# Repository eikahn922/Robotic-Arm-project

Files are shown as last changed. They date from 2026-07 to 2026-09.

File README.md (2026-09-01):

# Robotic Arm Project

This repository documents the mechanical design, engineering analysis, and ROS 2 development of a robotic arm with three arm joints, a wrist, and a mimic-driven gripper. It is organized so each stage can be reviewed and reproduced independently.

## Project artifacts

| Area | Artifact | Description |
| --- | --- | --- |
| Active timeline | [3-DOF Robotic Arm Project Timeline](docs/project-workflow/PROJECT_TIMELINE.md) | Daily development plan through August 18, including remote-work constraints and completion criteria. |
| Physical build | [Parts List and Purchase Tracker](physical-build/README.md) | Torque-driven actuator selection, power distribution, wiring, fasteners, camera plan, and purchase tracker. |
| ROS 2 progress | [ROS 2 Progress](ROS_PROGRESS.md) | Recruiter-friendly milestone log covering the completed setup, URDF/Xacro model, RViz result, lessons learned, and next steps. |
| ROS 2 package | [robot_arm_description](ros2_ws/src/robot_arm_description) | Reproducible ROS 2 Jazzy package containing the complete CAD geometry — base, waist, upper arm, forearm, wrist, and all seven gripper part instances — with five commanded joints and a mimic gripper side. |
| Ubuntu VM guide | [VM Handoff](docs/VM_HANDOFF.md) | Exact Ubuntu 24.04 ARM64 commands to update, build, launch, and troubleshoot the RViz visualization. |
| Control & simulation | [Simulation Guide](docs/SIMULATION.md) | Per-layer status, `ros2_control` test commands, and the list of assumptions not yet verified at runtime. |
| Model validation | [validate_model.py](ros2_ws/src/robot_arm_description/test/validate_model.py) | Dependency-free static validation of the URDF tree, meshes, collision, inertials, and controller configuration. |
| ROS 2 base mesh | [base_link.stl](ros2_ws/src/robot_arm_description/STL/base_link.stl) | Meter-scaled binary STL exported from SolidWorks for the fixed robot base. |
| ROS 2 waist mesh | [waist_link.stl](ros2_ws/src/robot_arm_description/STL/waist_link.stl) | Meter-scaled binary STL exported from SolidWorks for the rotating waist link. |
| ROS 2 upper-arm mesh | [upper_arm_link.stl](ros2_ws/src/robot_arm_description/STL/upper_arm_link.stl) | Meter-scaled binary STL with a shoulder-centered origin and 120 mm shoulder-to-elbow spacing. |
| ROS 2 forearm mesh | [forearm_link.stl](ros2_ws/src/robot_arm_description/STL/forearm_link.stl) | Millimeter-scaled binary STL for Link #2, converted to meters and aligned to the STEP assembly in Xacro. |
| Project workflow | [Robotic Arm Project Workflow](docs/project-workflow/Robotic-Arm-Project-Workflow.pdf) | Detailed engineering and implementation workflow for the project. |
| Engineering analysis | [Torque and Servo Sizing Analysis](analysis/README.md) | Formula-driven shoulder and elbow torque calculations, assumptions, results, and validation plan. |
| Calculation workbook | [3DOF Robotic Arm Torque & Servo Sizing Analysis](analysis/3DOF-Robotic-Arm-Torque-Servo-Sizing-Analysis.xlsx) | Downloadable workbook containing the full servo-sizing calculation model. |
| Final assembly | [Robot Arm Final Assembly](cad/assembly/Robot-Arm-Final-Assembly.SLDASM) | Complete SolidWorks assembly for the robot arm. |
| CAD — base | [Robot Arm Base v1](cad/base/Robot-Arm-Base-v1.SLDPRT) | SolidWorks part model for the robot arm's structural base. |
| CAD — gripper gear | [gearRobotArm.SLDPRT](cad/gripper/gearRobotArm.SLDPRT) | SolidWorks part model for the gripper gear. |
| CAD — gripper connecting link | [Robot Arm Gripper Connecting Link](cad/all-links/Robot-Arm-Gripper-Connecting-Link.SLDPRT) | SolidWorks part model for the gripper connecting link. |
| CAD — gripper first link | [Robot Arm Gripper First Link](cad/gripper/Robot-Arm-Gripper-First-Link.SLDPRT) | SolidWorks part model for the first gripper link. |
| CAD — gripper link | [Robot Arm Gripper Link 1](cad/gripper/Robot-Arm-Gripper-Link-1.SLDPRT) | SolidWorks part model for the gripper connection link. |
| CAD — link 1 | [Robot Arm Link 1](cad/all-links/Robot-Arm-Link-1.SLDPRT) | SolidWorks part model for the first structural arm link. |
| CAD — link 2 | [Robot Arm Link 2](cad/all-links/Robot-Arm-Link-2.SLDPRT) | SolidWorks part model for the second structural arm link. |
| CAD — link 3 | [Robot Arm Link 3](cad/all-links/Robot-Arm-Link-3.SLDPRT) | SolidWorks part model for the third structural arm link. |
| CAD — servo | [MG996R_servo.SLDPRT](cad/servo/MG996R_servo.SLDPRT) | SolidWorks part model for the MG996R servo. |
| CAD — servo | [SG90 - Micro Servo 9g - Tower Pro.1.SLDPRT](cad/servo/SG90%20-%20Micro%20Servo%209g%20-%20Tower%20Pro.1.SLDPRT) | SolidWorks part model for the Tower Pro SG90 micro servo. |
| CAD — waist | [Robot Arm Waist v1](cad/waist/Robot-Arm-Waist-v1.SLDPRT) | SolidWorks part model for the rotating waist component. |

## Repository structure

```text
.
├── cad/
│   ├── README.md
│   ├── assembly/
│   │   ├── README.md
│   │   └── Robot-Arm-Final-Assembly.SLDASM
│   ├── base/
│   │   └── Robot-Arm-Base-v1.SLDPRT
│   ├── gripper/
│   │   ├── Robot-Arm-Gripper-First-Link.SLDPRT
│   │   ├── Robot-Arm-Gripper-Link-1.SLDPRT
│   │   └── gearRobotArm.SLDPRT
│   ├── all-links/
│   │   ├── Robot-Arm-Gripper-Connecting-Link.SLDPRT
│   │   ├── Robot-Arm-Link-1.SLDPRT
│   │   ├── Robot-Arm-Link-2.SLDPRT
│   │   └── Robot-Arm-Link-3.SLDPRT
│   ├── servo/
│   │   ├── MG996R_servo.SLDPRT
│   │   └── SG90 - Micro Servo 9g - Tower Pro.1.SLDPRT
│   └── waist/
│       └── Robot-Arm-Waist-v1.SLDPRT
├── analysis/
│   ├── README.md
│   └── 3DOF-Robotic-Arm-Torque-Servo-Sizing-Analysis.xlsx
├── physical-build/
│   └── README.md
├── ros2_ws/
│   ├── README.md
│   └── src/
│       └── robot_arm_description/
│           ├── CMakeLists.txt
│           ├── package.xml
│           ├── STL/
│           │   ├── README.md
│           │   ├── base_link.stl
│           │   ├── upper_arm_link.stl
│           │   └── waist_link.stl
│           ├── launch/
│           ├── rviz/
│           └── urdf/
├── ROS_PROGRESS.md
└── docs/
    ├── images/
    │   └── ros/
    │       └── rviz-placeholder-arm.png
    └── project-workflow/
        ├── PROJECT_TIMELINE.md
        └── Robotic-Arm-Project-Workflow.pdf
```

## File formats

- `.SLDASM` files are native SolidWorks assemblies that reference component documents.
- `.SLDPRT` files are native SolidWorks part models.
- `.md` files contain repository-readable project plans and documentation.
- `.pdf` files contain project documentation suitable for viewing without CAD software.
- `.xlsx` files contain formula-driven engineering calculations and design inputs.
- `.xacro` files define parameterized robot links, joints, origins, axes, and limits for ROS 2.
- `.py` launch files start and configure the ROS 2 visualization nodes.
- `.stl` files contain meter-scaled binary geometry exported from SolidWorks for ROS visualization.

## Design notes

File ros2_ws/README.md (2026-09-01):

# ROS 2 Workspace

This directory contains the ROS 2 Jazzy packages for the 3-DOF robotic arm. See [ROS_PROGRESS.md](../ROS_PROGRESS.md) for the completed milestones, lessons learned, and next steps.

## Build and launch

Copy or clone this repository into an Ubuntu 24.04 environment with ROS 2 Jazzy installed, then run:

```bash
cd ros2_ws
colcon build --symlink-install --packages-select robot_arm_description
source install/setup.bash
LIBGL_ALWAYS_SOFTWARE=1 \
MESA_LOADER_DRIVER_OVERRIDE=llvmpipe \
QT_X11_NO_MITSHM=1 \
ros2 launch robot_arm_description display.launch.py
```

The three environment variables force software rendering, which the current UTM virtual machine
requires. They may be omitted on a native Linux system with working OpenGL acceleration.

See [docs/VM_HANDOFF.md](../docs/VM_HANDOFF.md) for the full Ubuntu VM update, build, launch, and
troubleshooting procedure.

## What this package currently is

An RViz **kinematic visualization**: `robot_state_publisher` publishes the TF tree from the URDF,
`joint_state_publisher_gui` provides sliders, and RViz draws the meshes. There is no physics engine.
Gazebo Sim and `ros2_control` are not implemented yet.

## Joint controls

`joint_state_publisher_gui` exposes six sliders:

| Joint | Type | Axis | Limits (rad) | Basis |
| --- | --- | --- | --- | --- |
| `base_yaw_joint` | revolute | `0 0 1` | −3.1416 to 3.1416 | provisional |
| `shoulder_joint` | revolute | `0 1 0` | −1.5708 to 1.5708 | provisional |
| `elbow_joint` | revolute | `0 1 0` | −2.0944 to 2.0944 | provisional |
| `wrist_roll_joint` | revolute | `0 0 1` | −3.1416 to 3.1416 | provisional |
| `wrist_pitch_joint` | revolute | `1 0 0` | −1.5708 to 1.5708 | provisional |
| `gripper_joint` | revolute | `0 0 1` | 0 to 0.75 | provisional; 0 = closed, 0.75 = 51.8 mm |

Three joints follow `gripper_joint` through URDF `mimic` tags and are deliberately not independent
controls: `right_gripper_joint` (opposing side) and `left_finger_joint` / `right_finger_joint`
(the parallelogram counter-rotation that keeps the jaw faces from fanning open).

## Link tree

```text
base_link
└── base_yaw_joint      (revolute)  → waist_link
    └── shoulder_joint  (revolute)  → upper_arm_link
        └── elbow_joint (revolute)  → forearm_link
            └── wrist_roll_joint  (revolute) → wrist_link
                └── wrist_pitch_joint (revolute) → gripper_base_link
                    ├── gripper_joint        (revolute) → left_gear_link
                    │   └── left_finger_joint  (mimic)  → left_finger_link
                    └── right_gripper_joint  (mimic)    → right_gear_link
                        └── right_finger_joint (mimic)  → right_finger_link
```

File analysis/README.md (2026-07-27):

# Torque and Servo Sizing Analysis

This folder documents the preliminary static torque analysis used to evaluate the MG996R servos for the shoulder and elbow joints of the 3-DOF robotic arm.

## Analysis artifacts

- [Calculation workbook](3DOF-Robotic-Arm-Torque-Servo-Sizing-Analysis.xlsx) — formula-driven engineering workbook with inputs, source notes, joint calculations, utilization, safety margins, and a comparison chart.
- [Live Google Sheet](https://docs.google.com/spreadsheets/d/17cgYGMoWEYcnl7br5cGeY7KRNHN3UeBQPRdlAbZkqd0/edit) — browser-accessible version of the same analysis.

## Method

The arm was evaluated in a conservative horizontal pose, where gravity produces the largest moment about the shoulder and elbow axes. For each joint, the static and design torques are calculated as:

```text
arm torque     = moving mass x gravity x center-of-mass radius
payload torque = payload mass x gravity x payload radius
static torque  = arm torque + payload torque
design torque  = static torque x safety factor
```

The model uses a 10 g payload representing a small foam ball, a safety factor of 2.0, and the MG996R advertised stall torque of 11 kgf-cm at 6 V. Masses and centers of mass come from the SolidWorks assembly after assigning PLA to the printed parts.

## Results

| Joint | Moving mass | COM radius | Static torque | Design torque | Servo utilization | Torque margin |
| --- | ---: | ---: | ---: | ---: | ---: | ---: |
| Elbow | 217.60 g | 76.46 mm | 1.94 kgf-cm | 3.88 kgf-cm | 35.3% | 2.83x |
| Shoulder | 297.31 g | 116.65 mm | 3.82 kgf-cm | 7.65 kgf-cm | 69.5% | 1.44x |

Both joints pass this preliminary static comparison. The shoulder is the limiting joint and therefore receives priority during physical testing.

## Engineering limitations and validation plan

- Advertised stall torque is a short-duration maximum, not a continuous operating rating.
- The current CAD masses treat modeled printed parts as solid PLA. Slicer-estimated printed masses should replace them after infill, wall count, and hardware are finalized.
- Wiring, fasteners, bearings, servo horns, and other unmodeled hardware must be added to the moving mass.
- The completed arm should be bench-tested at reduced command speed while measuring supply voltage, current draw, holding performance, temperature, and joint deflection.
- If the shoulder overheats, stalls, or sags, reduce reach or mass, add a spring/counterbalance, or select a higher-torque actuator.

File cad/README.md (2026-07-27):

# CAD Models

CAD files are grouped by robot subsystem so the repository can grow without mixing unrelated components.

## Final Assembly

- [`assembly/Robot-Arm-Final-Assembly.SLDASM`](assembly/Robot-Arm-Final-Assembly.SLDASM) contains the final robot arm assembly.
- [`assembly/README.md`](assembly/README.md) explains how to verify and package its external component references.

## Base

- [`base/Robot-Arm-Base-v1.SLDPRT`](base/Robot-Arm-Base-v1.SLDPRT) contains the first SolidWorks model of the structural base.

## Gripper

- [`gripper/gearRobotArm.SLDPRT`](gripper/gearRobotArm.SLDPRT) contains the gripper gear model.
- [`gripper/Robot-Arm-Gripper-First-Link.SLDPRT`](gripper/Robot-Arm-Gripper-First-Link.SLDPRT) contains the first gripper link.
- [`gripper/Robot-Arm-Gripper-Link-1.SLDPRT`](gripper/Robot-Arm-Gripper-Link-1.SLDPRT) contains the existing gripper link component.

## All Links

- [`all-links/Robot-Arm-Gripper-Connecting-Link.SLDPRT`](all-links/Robot-Arm-Gripper-Connecting-Link.SLDPRT) contains the gripper connecting link.
- [`all-links/Robot-Arm-Link-1.SLDPRT`](all-links/Robot-Arm-Link-1.SLDPRT) contains the first structural arm link.
- [`all-links/Robot-Arm-Link-2.SLDPRT`](all-links/Robot-Arm-Link-2.SLDPRT) contains the second structural arm link.
- [`all-links/Robot-Arm-Link-3.SLDPRT`](all-links/Robot-Arm-Link-3.SLDPRT) contains the third structural arm link.

## Servo

- [`servo/MG996R_servo.SLDPRT`](servo/MG996R_servo.SLDPRT) contains the MG996R servo model.
- [`servo/SG90 - Micro Servo 9g - Tower Pro.1.SLDPRT`](servo/SG90%20-%20Micro%20Servo%209g%20-%20Tower%20Pro.1.SLDPRT) contains the Tower Pro SG90 micro-servo model.

## Waist

- [`waist/Robot-Arm-Waist-v1.SLDPRT`](waist/Robot-Arm-Waist-v1.SLDPRT) contains the first SolidWorks model of the rotating waist component.

Future revisions should increment the version number while retaining older versions when they document meaningful design changes.

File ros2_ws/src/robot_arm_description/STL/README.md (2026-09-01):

# ROS link geometry

This directory stores one consistently named STL mesh for each rigid URDF link.

## Imported meshes

| Mesh | Export format | Dimensions | Coordinate-frame note |
| --- | --- | --- | --- |
| `base_link.stl` | Binary STL, meters | 121.21 × 56.00 × 121.25 mm | Origin is centered on the bottom face; the exported Y axis is up, so the URDF visual will apply a +90° X rotation to align it with ROS Z-up. |
| `waist_link.stl` | Binary STL, meters | 96.86 × 73.80 × 97.00 mm | Origin is centered on the bottom face; the exported Y axis is up, so the URDF visual will apply a +90° X rotation to align it with ROS Z-up. |
| `upper_arm_link.stl` | Binary STL, meters | 42.00 × 161.97 × 21.00 mm | Origin is the shoulder pivot. The mesh is Z-up and extends along +Y; the URDF applies a −90° Z rotation to align it with link +X. The shoulder-to-elbow spacing is 120 mm. |
| `forearm_link.stl` | Binary STL, millimeters | 125.00 × 38.00 × 27.00 mm | Exported as SolidWorks Link #2 with its mesh origin shifted +63, +19, +8 mm from the STEP component frame. The Xacro converts millimeters to meters and compensates for that export offset before applying the STEP-derived assembly placement. |
| `wrist_link.stl` | Binary STL, millimeters | 33.00 × 28.00 × 46.00 mm | Extracted as `link#3RoboticArm` directly from `RobotArmAssembly (1).STEP` in its component-local frame. |
| `gripper_base.stl` | Binary STL, millimeters | 53.30 × 28.00 × 77.00 mm | Supplied gripper-first-link export, normalized from assembly coordinates into its STEP component-local frame. |
| `gripper_gear.stl` | Binary STL, millimeters | 26.70 × 10.00 × 49.37 mm | Normalized gear mesh referenced twice at the two STEP gear occurrences. |
| `gripper_connecting_link.stl` | Binary STL, millimeters | 39.00 × 8.00 × 4.00 mm | Normalized connecting-link mesh referenced twice at the two STEP occurrences. |
| `gripper_finger.stl` | Binary STL, millimeters | 65.16 × 17.87 × 4.50 mm | Normalized finger mesh referenced twice at the two STEP occurrences. |

> **Dimension note.** The connecting-link and finger rows list the axis-aligned bounding box of the
> *normalized* mesh as committed here. Earlier revisions of this table listed the bounding box of the
> raw SolidWorks export, before the mesh was rotated into its STEP component-local frame. A rigid
> rotation does not change the part, but it does change its axis-aligned extents, which is why the
> numbers moved.

## Link assignment

Each mesh is now attached to a specific moving URDF link rather than to one combined rigid body:

| Mesh | URDF link | Instances |
| --- | --- | --- |
| `base_link.stl` | `base_link` | 1 |
| `waist_link.stl` | `waist_link` | 1 |
| `upper_arm_link.stl` | `upper_arm_link` | 1 |
| `forearm_link.stl` | `forearm_link` | 1 |
| `wrist_link.stl` | `wrist_link` | 1 |
| `gripper_base.stl` | `gripper_base_link` | 1 |
| `gripper_gear.stl` | `left_gear_link`, `right_gear_link` | 2 |
| `gripper_connecting_link.stl` | `left_gear_link`, `right_gear_link` | 2 |
| `gripper_finger.stl` | `left_finger_link`, `right_finger_link` | 2 |

The gear, connecting link, and finger meshes are each referenced twice on purpose: the two gripper
sides are separate STEP occurrences of the same part.

The full neutral-pose CAD geometry is represented, and the wrist and gripper now articulate. Each
gripper side rotates as one rigid gear/connector/finger group; see the Xacro comments for why the
real geared four-bar cannot be expressed directly in URDF.

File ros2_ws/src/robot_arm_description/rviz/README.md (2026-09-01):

# RViz configurations

| File | Purpose |
| --- | --- |
| `robot_arm.rviz` | Normal visual display. Meshes opaque, collision hidden, TF off. |
| `robot_arm_collision.rviz` | Collision verification. Collision primitives drawn with the visual meshes at 35% alpha so the boxes and cylinder show through. |

Both use `base_link` as the fixed frame and read the model from `/robot_description`.

Launch the normal view:

```bash
ros2 launch robot_arm_description display.launch.py
```

Launch the collision view:

```bash
ros2 launch robot_arm_description display.launch.py show_collision:=true
```

Or point RViz at any config explicitly:

```bash
ros2 launch robot_arm_description display.launch.py rviz_config:=/absolute/path/to/config.rviz
```

Previously the launch file borrowed `urdf_launch`'s stock `urdf.rviz`. These configs are committed so
display settings are under version control.

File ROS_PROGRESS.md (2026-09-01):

# ROS 2 Progress — 3-DOF Robotic Arm

## Current milestone

- Built a working ROS 2 Jazzy development environment on Ubuntu 24.04 ARM64.
- Created and validated a reusable ROS 2 robot-description package.
- Modeled the arm as an eight-link URDF/Xacro kinematic chain with five commanded joints and one mimic joint.
- Published the robot state and TF tree and rendered the placeholder arm successfully in RViz.
- Integrated the SolidWorks base, waist, upper-arm, forearm, wrist, and complete neutral-pose gripper geometry into the robot model.
- Extracted a 120 mm shoulder-to-elbow spacing from the upper-arm CAD geometry.
- Split the rigid `wrist_gripper_link` into `wrist_link`, `gripper_base_link`, and two moving gripper sides.
- Added `wrist_roll_joint`, `wrist_pitch_joint`, and `gripper_joint`, with three mimic joints driving
  the opposing gripper side and the two-finger parallelogram.
- Added fitted collision geometry and mesh-derived inertial properties for all ten links.
- Added a `ros2_control` configuration with mock hardware, written but not yet run.
- Current phase: run the model in the VM — verify the five joint controls in RViz, then the mock control stack.

> **Terminology.** This is an RViz *kinematic visualization*, not a physics simulation. It runs
> `robot_state_publisher`, `joint_state_publisher_gui`, and RViz. Gazebo Sim and `ros2_control` are
> not implemented yet, so nothing here computes mass, contact, or gravity.

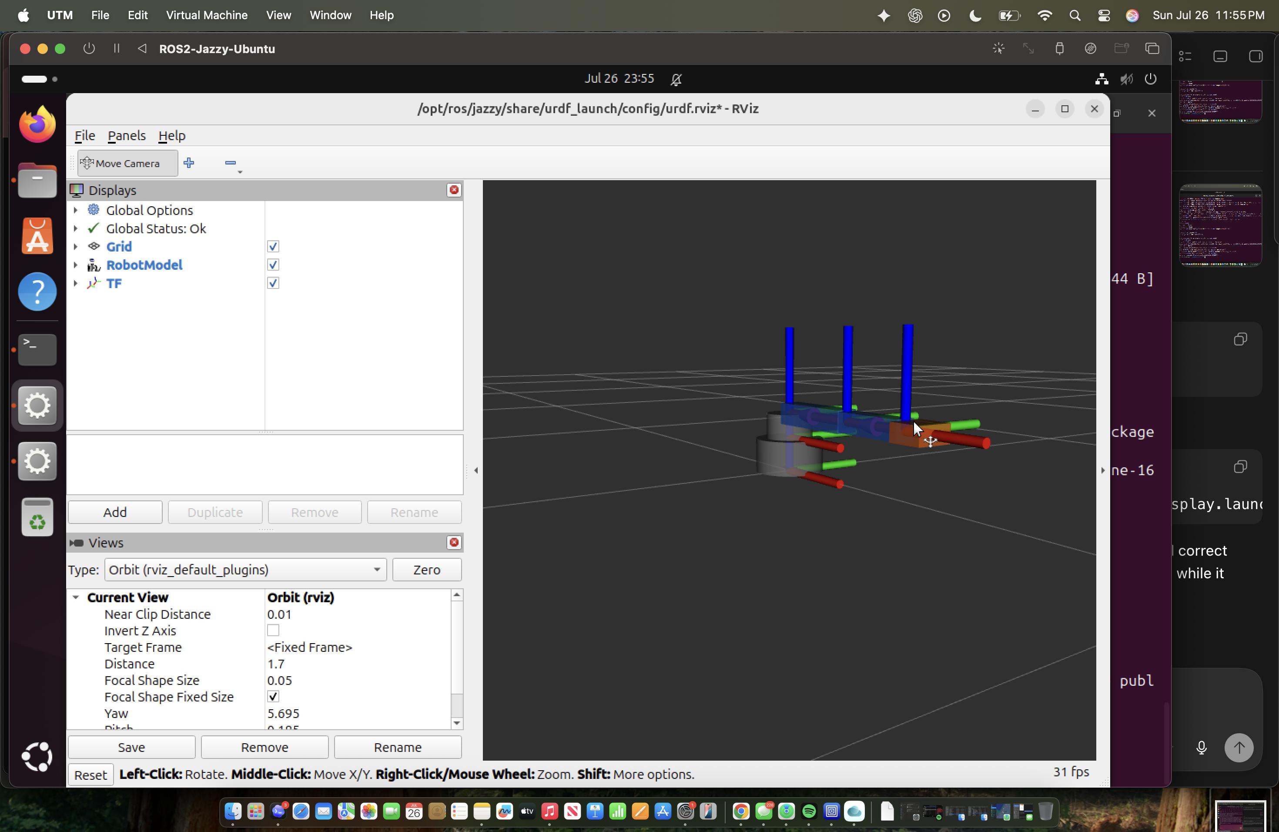
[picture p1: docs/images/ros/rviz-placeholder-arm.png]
Placeholder 3-DOF arm rendered in RViz


## Step 1 — Set up the ROS 2 environment

**Completed**

- Created an Ubuntu 24.04 ARM64 virtual machine with UTM on an Apple Silicon Mac.
- Installed ROS 2 Jazzy Desktop and the ROS development tools.
- Configured the shell to source ROS automatically.
- Verified node-to-node communication with the ROS talker/listener examples.

**What I learned**

- How ROS 2 packages are installed and sourced in a Linux environment.
- How nodes communicate through topics using a publisher/subscriber model.
- How to diagnose ARM64 package, shell, and software-rendering issues in a virtual machine.

## Step 2 — Create the workspace and package

**Completed**

- Created a colcon workspace at `~/robot_arm_ws`.
- Created the `robot_arm_description` package using `ament_cmake`.
- Added `urdf`, `STL`, `launch`, and `rviz` resource directories.
- Configured CMake to install the robot-description resources with the package.

**What I learned**

- The purpose of the `src`, `build`, `install`, and `log` workspace directories.
- How `colcon`, `ament_cmake`, `package.xml`, and `CMakeLists.txt` work together.
- Why a workspace must be rebuilt and sourced after package changes.

## Step 3 — Build and validate the first URDF/Xacro model

**Completed**

- Defined the initial kinematic chain:
  - `base_link`
  - `waist_link`
  - `upper_arm_link`
  - `forearm_link`
  - `wrist_gripper_link`
- Defined three revolute joints: base yaw, shoulder pitch, and elbow pitch.
- Added provisional joint origins, rotation axes, and motion limits.
- Used Xacro properties for reusable arm dimensions.
- Generated a URDF and verified the XML and link/joint tree with `check_urdf`.

**What I learned**

- How URDF represents a robot as a parent-child tree of links and joints.
- How joint origins, axes, and limits determine the arm's motion.
- How Xacro makes dimensions and repeated model elements easier to maintain.
- How to validate a model before attempting visualization or control.

## Step 4 — Publish and visualize the robot

**Completed**

- Used `robot_state_publisher` to publish the robot's link transforms.
- Used `joint_state_publisher_gui` to generate test joint positions.
- Visualized the robot model and TF axes in RViz.
- Configured software OpenGL rendering for reliable RViz operation in UTM.
- Corrected a launch parameter type issue by passing the generated URDF as an explicit string.

**What I learned**

- The difference between joint states and the TF transform tree.
- How `robot_state_publisher`, `joint_state_publisher_gui`, and RViz work together.
- How to interpret RViz fixed frames, RobotModel status, and TF output while debugging.
- How a ROS 2 launch file starts and configures several nodes as one system.

## Reproduce the current milestone

```bash
cd ~/robot_arm_ws
colcon build --symlink-install --packages-select robot_arm_description
source install/setup.bash
LIBGL_ALWAYS_SOFTWARE=1 ros2 launch robot_arm_description display.launch.py
```

## Next steps

### Step 5 — Export the SolidWorks geometry

**Completed so far**

- Exported the base, waist, and upper arm as meter-scaled binary STL files; the forearm, wrist, and normalized gripper parts remain in SolidWorks millimeters and are scaled by Xacro.
- Validated all nine unique mesh files' dimensions, orientation, binary structure, watertightness, and reference origin before integration.
- Kept the upper-arm origin at the shoulder pivot and measured a 120 mm shoulder-to-elbow distance from the CAD geometry.
- Derived the forearm transform from the STEP assembly and converted its millimeter geometry to ROS meters in Xacro.
- Added all nine unique meshes to `robot_arm_description/STL` with documented ROS frame corrections; the gear, connecting-link, and finger meshes are each instantiated twice from the STEP assembly.

**What I learned**

- How STL export units affect robot scale in RViz.
- Why a joint-centered mesh origin makes URDF placement and motion easier to understand.
- How to correct SolidWorks-to-ROS axis differences using a URDF `origin` rotation instead of modifying the CAD geometry.
- How to validate mesh dimensions and orientation before debugging them in ROS.

**Remaining**

- Verify the complete wrist and gripper geometry in RViz against the STEP assembly.

### Step 6 — Match the ROS model to the CAD assembly

- Replaced the placeholder base, waist, upper arm, and forearm with their corresponding SolidWorks meshes.
- Updated the provisional shoulder-to-elbow distance from 220 mm to the CAD-derived 120 mm value.
- Verify the base, waist, upper-arm, and forearm meshes together in RViz.
- Completed: replaced the gripper placeholder with Link #3 and all seven gripper part instances from the CAD assembly.
- Measure and enter the remaining exact joint origins and rotation axes.
- Replace provisional motion limits with the physical servo/link limits.
- Confirm that each RViz joint moves in the correct direction without separating the assembly.

### Step 6b — Split the wrist and gripper into moving joints

**Completed**

- Replaced the single fixed `wrist_gripper_link` with six links: `wrist_link`, `gripper_base_link`,
  `left_gear_link`, `left_finger_link`, `right_gear_link`, and `right_finger_link`.
- Six commanded joints: base yaw, shoulder, elbow, `wrist_roll_joint`, `wrist_pitch_joint`, and
  `gripper_joint`. Three mimic joints keep the rest passive, so the GUI shows exactly six sliders.
- Every joint's zero position is the STEP neutral pose. A static check confirms the split model
  reproduces the original single-link placement of all twelve visuals to within 1.04 nanometres,
  which is the rounding of the previous file's nine-decimal literals, not a modelling error.

**Wrist: two axes, corrected**

- An earlier revision made the wrist a *pitch* joint. That was wrong. Testing each wrist-frame axis
  against the forearm's long axis gives X 0.011, Y 0.011, **Z 0.9999** — so Z is the roll axis and
  the others only pitch. `wrist_roll_joint` now rolls the gripper about the forearm's own axis.
- The pitch belongs one joint further out, where a fixed mount used to be. `wrist_pitch_joint` uses
  the gripper-base X axis, which is exactly perpendicular to the roll axis (dot product 0.0000) and
  parallel to the jaw-opening direction, so the jaws stay level as the gripper tilts.

**Gripper: parallelogram, not scissors**

- The real mechanism is a geared four-bar closed loop, which URDF cannot express. Each side is now
  split into a gear body and a finger, with the finger counter-rotating against its gear through a
  mimic joint. The finger swings out along the gear's arc while its orientation stays fixed.
- The finger mimic multiplier is **+1**, not −1, because each finger frame's Z axis is anti-parallel
  to its gear frame's Z; a +1 rotation there is a −1 rotation about the gear axis.
- Measured effect: the angle between the two fingers now holds constant at 30.1° across the entire
  range (spread 0.00°). The previous rigid-block model fanned from 30.8° to 80.4° — visibly wrong in
  RViz, and the reason the gripper appeared to grip in the wrong direction.
- Both gear frames share one spin axis: their local Z axes are exactly anti-parallel in the
  gripper-base frame (dot product −1.000000), the meshing-gear signature, so the side mimic
  multiplier is +1 and the two sides counter-rotate in world space.

**Remaining approximation**

- The connecting link is carried rigidly with its gear rather than solved as a true four-bar. It sits
  correctly at zero but does not articulate exactly. Fixing this properly needs a closed-loop solver
  or a fitted mimic ratio measured from the CAD.

**Provisional values, not measurements**

- `wrist_roll_joint` ±3.1416 rad, `wrist_pitch_joint` ±1.5708 rad, `gripper_joint` 0 to 0.75 rad.
  The gripper upper limit is sized so the fingertips reach 51.8 mm, enough for the 2 inch foam ball
  in `analysis/`. All three are conservative choices from geometry, not measured mechanical stops.

### Step 7 — Add engineering properties

**Completed: collision geometry**

- Added one simplified collision primitive per physical link, fitted to the committed meshes rather
  than hand-guessed.
- `base_link` uses a cylinder; the mesh is genuinely round (40.5% of its vertices lie in the outer
  10% of radius) and a cylinder is 21% tighter than the bounding box.
- `waist_link` uses a box. It looks round but is not: only 8% of vertices lie in the outer 10% of
  radius, so a cylinder would be a mere 8% tighter and the box is the simpler primitive.
- The upper arm, forearm, wrist, and gripper base use oriented boxes sized to each mesh's own
  bounding box, so the box inherits the mesh's orientation instead of inflating an axis-aligned one.
- Each gripper side gets collision on the **finger only**. The gears and connecting links are
  internal mechanism that mesh and overlap by design; giving them collision geometry would create
  permanent contact in a physics engine for no benefit.
- A static check samples every visual mesh and confirms 100% of sampled vertices lie inside the
  corresponding collision primitive, and that the internal-mechanism meshes are deliberately
  uncovered.

**Known, expected overlap**

- The left and right finger collision boxes intersect at the neutral pose, because the gripper is
  closed there (2.65 mm between fingertips). Self-collision between `left_finger_link` and
  `right_finger_link` must therefore be disabled downstream — via `self_collide` in Gazebo and the
  SRDF self-collision matrix in MoveIt. This is expected, not a defect.
- `left_gear_link` and `right_gear_link` carry inertia but **no** collision geometry at all. The gears
  and connecting links mesh and overlap by design, so collision there would create permanent contact.

**Fit quality**

- `gripper_base_link` is the loosest primitive at roughly 7.2x the true part volume, because the part
  is an open forked bracket. A convex hull would be tighter if grasp clearance becomes a problem.

**Completed: inertial properties**

- Every link now carries mass, centre of mass, and a full inertia tensor obtained by integrating the
  committed STL meshes (divergence theorem over the closed surface), multiplied by `pla_density`.
- The stored numbers are per-unit-density volume integrals, so changing `pla_density` alone rescales
  every mass *and* every inertia correctly. That matters because workbook validation item 1 requires
  replacing the solid-model density with slicer estimates once infill and walls are chosen.
- Independent cross-check: this method gives the upper arm **79.78 g**. The analysis workbook implies
  **79.71 g** for the same part (297.31 g shoulder-moving minus 217.60 g elbow-moving). Agreement is
  0.1%, which validates both the mesh integration and the 1240 kg/m³ density from two directions.
- Every tensor is positive-definite (Sylvester's criterion) and every set of principal moments
  satisfies the triangle inequality, so all eight are physically realisable rigid bodies.
- Total printed-part mass is 435.8 g.

**Known gap, deliberately not filled**

- These are **printed-part masses only**. The workbook's moving-mass figures exceed the mesh sums by
  a near-constant **82.5 g** at both the shoulder and the elbow — servo, fastener, and hardware mass
  distal to the elbow. It is not distributed across links here, because workbook validation item 3
  ("confirm the servo body mounting side for each joint") is still open. Assigning it without that
  confirmation would be a guess dressed up as a measurement. Add it once mounting sides are known.

**Remaining**

- Compare calculated joint torque requirements against the selected servos once servo masses are
  placed. The workbook already reports the shoulder as the limiting joint at 69.5% design
  utilisation with a 1.44x stall margin, and that figure already includes the hardware mass.

### Step 8 — Add control and simulation

**Completed: `ros2_control` configuration (written, not yet run)**

- Added a `ros2_control` hardware interface, controller YAML, and a separate control launch path.
  `robot_arm.urdf.xacro` stays free of control tags; `robot_arm_control.urdf.xacro` layers the
  interface on top, so a broken controller cannot break the working visualization.
- Mock hardware (`mock_components/GenericSystem`) is the default, so the whole control stack can be
  exercised with no physics engine and no GPU. On an ARM64 VM with software rendering that is far
  cheaper than debugging controllers and Gazebo simultaneously.
- Controllers: `joint_state_broadcaster`, an `arm_controller` over base yaw/shoulder/elbow/wrist, and
  a `gripper_controller` over `gripper_joint`. The arm controller starts only after the broadcaster
  exits successfully, so joint states exist before any trajectory is commanded.
- `right_gripper_joint` is deliberately absent from both the `ros2_control` block and the controller
  YAML, because a mimic joint must not have an independent command interface.

> **Not verified.** No controller has been loaded, no plugin name confirmed, no gain tuned. See
> [docs/SIMULATION.md](docs/SIMULATION.md) for the CLI test commands and the explicit list of
> unverified assumptions — the most fragile being that `ros2_control` propagates URDF `mimic` joints
> automatically.

**Remaining**

- Run the mock-hardware control stack in the VM and confirm the mimic side follows.
- Add Gazebo Sim: world, ground plane, spawn, `gz_ros2_control`, and a pickup target.
- Add MoveIt 2 inverse kinematics, an RGB-D camera, OpenCV ball detection, and autonomous
  pick-and-place.
- Add a microcontroller interface for servo commands and joint feedback.

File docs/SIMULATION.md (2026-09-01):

# Control and Simulation Guide

Status of each layer, and how to test it. Read the status column before assuming something works.

| Layer | State | Verified? |
| --- | --- | --- |
| RViz kinematic visualization | Implemented | Statically validated; **RViz rendering not yet run** |
| Collision geometry | Implemented | Statically validated |
| Inertial properties | Implemented | Statically validated; no physics engine has consumed them |
| `ros2_control` (mock hardware) | Implemented | **Never run** — plugin and parameter names unverified |
| `ros2_control` (Gazebo) | Description only | Not implemented — no world, no spawn, no `gz_ros2_control` launch |
| Gazebo Sim | Not implemented | — |
| MoveIt 2 | Not implemented | — |
| RGB-D camera | Not implemented | — |
| Ball detection | Not implemented | — |
| Autonomous pick-and-place | Not implemented | — |

Everything below the `ros2_control (mock)` row does not exist yet. Do not describe this project as
having a Gazebo simulation.

## Two separate entry points

The visualization path and the control path are deliberately separate, so a broken controller cannot
break the thing that already works.

| File | Purpose | Model |
| --- | --- | --- |
| `launch/display.launch.py` | RViz + slider GUI, no controllers | `urdf/robot_arm.urdf.xacro` |
| `launch/control.launch.py` | `controller_manager` + controllers | `urdf/robot_arm_control.urdf.xacro` |

`robot_arm.urdf.xacro` carries no `ros2_control` tags at all. The control variant includes it and
adds the hardware interface on top.

## Static validation (runs anywhere, no ROS)

```bash
python3 ros2_ws/src/robot_arm_description/test/validate_model.py
```

## Build

```bash
cd ~/robot_arm_ws && colcon build --symlink-install --packages-select robot_arm_description --cmake-clean-cache
```

```bash
source ~/robot_arm_ws/install/setup.bash
```

## 1. Visualization only

```bash
LIBGL_ALWAYS_SOFTWARE=1 MESA_LOADER_DRIVER_OVERRIDE=llvmpipe QT_X11_NO_MITSHM=1 ros2 launch robot_arm_description display.launch.py
```

Show collision primitives instead (meshes drop to 35% alpha so the boxes show through):

```bash
LIBGL_ALWAYS_SOFTWARE=1 MESA_LOADER_DRIVER_OVERRIDE=llvmpipe QT_X11_NO_MITSHM=1 ros2 launch robot_arm_description display.launch.py show_collision:=true
```

## 2. Expand and check the control model

Do this before launching controllers — it catches xacro and URDF errors on their own:

```bash
ros2 run xacro xacro ~/robot_arm_ws/src/robot_arm_description/urdf/robot_arm_control.urdf.xacro hardware:=mock -o /tmp/arm_control.urdf && check_urdf /tmp/arm_control.urdf
```

Confirm the `ros2_control` block survived expansion, and that the mimic joint is *not* in it:

```bash
grep -A3 "<ros2_control" /tmp/arm_control.urdf && grep -c right_gripper_joint /tmp/arm_control.urdf
```

`right_gripper_joint` should appear in the `<joint>`/`<mimic>` model section but **not** inside
`<ros2_control>`.

## 3. Controllers on mock hardware — no simulator needed

This is the cheapest way to find controller problems on an ARM64 VM, because nothing here needs a
physics engine or a GPU.

```bash
LIBGL_ALWAYS_SOFTWARE=1 MESA_LOADER_DRIVER_OVERRIDE=llvmpipe QT_X11_NO_MITSHM=1 ros2 launch robot_arm_description control.launch.py
```

In a second terminal, confirm the controllers loaded and are active:

```bash
ros2 control list_controllers
```

Expect `joint_state_broadcaster`, `arm_controller`, and `gripper_controller`, all `active`.

List the command interfaces — there should be exactly six, and none for any mimic joint:

```bash
ros2 control list_hardware_interfaces
```

### Command each joint independently

Shoulder to +0.5 rad:

```bash
ros2 topic pub --once /arm_controller/joint_trajectory trajectory_msgs/msg/JointTrajectory "{joint_names: [base_yaw_joint, shoulder_joint, elbow_joint, wrist_roll_joint, wrist_pitch_joint], points: [{positions: [0.0, 0.5, 0.0, 0.0, 0.0], time_from_start: {sec: 2}}]}"
```

Base yaw to +1.0 rad:

```bash
ros2 topic pub --once /arm_controller/joint_trajectory trajectory_msgs/msg/JointTrajectory "{joint_names: [base_yaw_joint, shoulder_joint, elbow_joint, wrist_roll_joint, wrist_pitch_joint], points: [{positions: [1.0, 0.0, 0.0, 0.0, 0.0], time_from_start: {sec: 2}}]}"
```

Open the gripper (0 is closed, 0.30 is open):

```bash
ros2 topic pub --once /gripper_controller/joint_trajectory trajectory_msgs/msg/JointTrajectory "{joint_names: [gripper_joint], points: [{positions: [0.75], time_from_start: {sec: 1}}]}"
```

Close it again:

```bash
ros2 topic pub --once /gripper_controller/joint_trajectory trajectory_msgs/msg/JointTrajectory "{joint_names: [gripper_joint], points: [{positions: [0.0], time_from_start: {sec: 1}}]}"
```

### Confirm the mimic side follows

While the gripper is part-open, both sides should report the same angle:

```bash
ros2 topic echo /joint_states --once
```

`gripper_joint`, `right_gripper_joint`, `left_finger_joint`, and `right_finger_joint` should all hold equal positions. If `right_gripper_joint` stays
at zero while `gripper_joint` moves, mimic propagation is not working in the installed
`ros2_control` version and the gripper will need an explicit second command interface instead.

Confirm the transform chain reaches both fingers:

```bash
ros2 run tf2_ros tf2_echo base_link left_finger_link
```

## Unverified assumptions

These are written from documentation, not from a run. Check them first if something fails:

1. `mock_components/GenericSystem` is the correct mock plugin name for the installed `ros2_control`.
2. `gz_ros2_control/GazeboSimSystem` is the correct Gazebo Sim plugin for ROS 2 Jazzy.
3. `ros2_control` propagates URDF `<mimic>` joints automatically, so `right_gripper_joint` needs no
   command interface. **This is the assumption most likely to be wrong**, and the joint-state check
   above is the test for it.
4. The controller parameter names in `config/controllers.yaml` match the installed
   `joint_trajectory_controller`.
5. Controller gains and tolerances are provisional. They have never been tuned against real dynamics.

## Next steps toward Gazebo

Not started. In order: a world file with ground plane and lighting, a spawn launch file, the
`gz_ros2_control` plugin block, then controller startup against the simulated hardware. Begin
headless (`gz sim -s`) — the VM is ARM64 with LLVMpipe software rendering, and Gazebo physics plus
camera rendering is a substantially harder proposition than RViz. Add the RGB-D camera only after
physics and control are stable.

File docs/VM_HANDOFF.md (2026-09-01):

# Ubuntu VM Handoff — Build, Launch, and Troubleshoot

Keep this file current whenever package paths, link names, launch files, or simulation commands
change.

## Development environment

| Item | Value |
| --- | --- |
| Host | Apple Silicon Mac |
| Virtualization | UTM / QEMU |
| Guest OS | Ubuntu 24.04 ARM64 |
| ROS distribution | ROS 2 Jazzy |
| Linux username | `ezra` |
| VM hostname | `ezra-QEMU-Virtual-Machine` |
| ROS workspace | `/home/ezra/robot_arm_ws` |
| GitHub clone | `/home/ezra/Robotic-Arm-project-main` |
| ROS package | `robot_arm_description` |
| Package source | `/home/ezra/robot_arm_ws/src/robot_arm_description` |
| Installed package | `/home/ezra/robot_arm_ws/install/robot_arm_description` |

## Terminology

The current program is an RViz **kinematic visualization**, not a physics simulation. It runs
`robot_state_publisher`, `joint_state_publisher_gui`, and RViz. Gazebo Sim and `ros2_control` have
not been implemented. Do not call this a Gazebo simulation.

## Update the VM from GitHub

Stop any running ROS launch with Ctrl+C, then:

```bash
git -C ~/Robotic-Arm-project-main pull --ff-only origin main
```

Check the retrieved version:

```bash
git -C ~/Robotic-Arm-project-main log --oneline -1
```

Copy the package from the clone into the ROS workspace:

```bash
cp -a ~/Robotic-Arm-project-main/ros2_ws/src/robot_arm_description/. ~/robot_arm_ws/src/robot_arm_description/
```

Load ROS:

```bash
source /opt/ros/jazzy/setup.bash
```

Build:

```bash
cd ~/robot_arm_ws && colcon build --symlink-install --packages-select robot_arm_description --cmake-clean-cache
```

Load the built workspace:

```bash
source ~/robot_arm_ws/install/setup.bash
```

Confirm which package ROS will load:

```bash
ros2 pkg prefix robot_arm_description
```

Expected output: `/home/ezra/robot_arm_ws/install/robot_arm_description`

## Launch RViz and the joint controls

The VM requires software rendering:

```bash
LIBGL_ALWAYS_SOFTWARE=1 MESA_LOADER_DRIVER_OVERRIDE=llvmpipe QT_X11_NO_MITSHM=1 ros2 launch robot_arm_description display.launch.py
```

Keep this terminal open. Ctrl+C stops RViz, `robot_state_publisher`, and Joint State Publisher.

The launch file starts `robot_state_publisher`, `joint_state_publisher_gui`, and `rviz2`. Do not
start a second `joint_state_publisher_gui` while the launch file's instance is running — two
publishers on `/joint_states` make the sliders and model fight each other.

## Finding the slider window

Joint State Publisher opens as a separate Ubuntu window. If RViz covers it:

- Minimize RViz with the minus button, not the close button.
- Click the running gray gear icons in the Ubuntu dock.
- On a Mac keyboard, Option acts as Ubuntu Alt, so Option+Tab may switch windows after clicking
  inside the VM.
- Startup succeeded when the terminal logs contain `Got description, configuring robot` and
  `Centering`.

The "Zero" button in RViz resets the camera. It is not the Joint State Publisher Center button.

## RViz viewing

- Set Fixed Frame to `base_link`.
- Ensure RobotModel is enabled.
- Disable TF to hide the red/green/blue axis markers.
- Use the mouse wheel to zoom.
- Press Center in Joint State Publisher to return all movable joints to zero.

## Joint controls

Six sliders are exposed:

| Slider | Type | Notes |
| --- | --- | --- |
| `base_yaw_joint` | revolute | base rotation |
| `shoulder_joint` | revolute | pitch |
| `elbow_joint` | revolute | pitch |
| `wrist_roll_joint` | revolute | rolls the gripper about the forearm's long axis |
| `wrist_pitch_joint` | revolute | tilts the gripper up and down |
| `gripper_joint` | revolute | 0 = closed (STEP neutral), 0.75 = open (51.8 mm) |

Three joints are `mimic` joints and must **not** appear as sliders: `right_gripper_joint`,
`left_finger_joint`, and `right_finger_joint`. If any of them shows up, the mimic tags were lost —
rebuild with `--cmake-clean-cache`.

## Diagnostics

Confirm the transform tree reaches the end of the arm. The old `wrist_gripper_link` no longer
exists; use the new link names:

```bash
ros2 run tf2_ros tf2_echo base_link left_finger_link
```

Other useful frames: `wrist_link`, `gripper_base_link`, `left_gear_link`, `right_finger_link`.

Confirm joint states are publishing:

```bash
ros2 topic echo /joint_states
```

Check publisher count — there should be exactly one during RViz testing:

```bash
ros2 topic info /joint_states --verbose
```

Confirm the robot description exists:

```bash
ros2 topic echo /robot_description --once
```

Verify installed meshes:

```bash
ls -lh ~/robot_arm_ws/install/robot_arm_description/share/robot_arm_description/STL/
```

The mesh list should contain nine files: `base_link.stl`, `waist_link.stl`, `upper_arm_link.stl`,
`forearm_link.stl`, `wrist_link.stl`, `gripper_base.stl`, `gripper_gear.stl`,
`gripper_connecting_link.stl`, `gripper_finger.stl`.

Validate the model without launching RViz:

```bash
ros2 run xacro xacro ~/robot_arm_ws/src/robot_arm_description/urdf/robot_arm.urdf.xacro -o /tmp/robot_arm.urdf && check_urdf /tmp/robot_arm.urdf
```

## Common problems

**RViz opens but the arm is missing.** Expand RobotModel and inspect Status. Confirm Fixed Frame is
`base_link`, the installed STL files exist, and `ros2 pkg prefix` points at the workspace install.
Rebuild with `--cmake-clean-cache`.

**The model is tiny.** Usually camera distance. Open Panels → Views, set Distance to about 0.5–1.0
and Focal Point near `0, 0, 0.1`.

**Joint State Publisher says it is waiting for robot_description.** It was started separately
without `robot_state_publisher`. Stop it and use the full `display.launch.py`.

**Sliders change but the model does not move.** Check for competing `/joint_states` publishers, stop
any manually launched Joint State Publisher, and relaunch once via `display.launch.py`.

**Graphics errors mention ZINK, EGL, or Mesa.** Use all three environment settings shown above.

**Newly added meshes do not appear.** Confirm the VM pulled the expected commit, copy the package
into `~/robot_arm_ws/src` again, rebuild with `--cmake-clean-cache`, re-source
`install/setup.bash`, and confirm the files exist under the installed package.

## Future Gazebo warning

Gazebo Sim has not been installed or configured for this repository. The VM is ARM64 and renders
RViz through LLVMpipe software rendering, so Gazebo physics plus camera rendering may be slow. When
Gazebo is added: begin with a headless server if rendering is unstable, test joint control without
the camera first, and add the RGB-D camera only after physics and `ros2_control` work.

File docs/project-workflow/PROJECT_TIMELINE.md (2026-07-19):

# 3-DOF Robotic Arm Project Timeline

Target completion: **August 18, 2026**

Maximum available time: **approximately 87 hours**

This schedule assumes up to three hours of work per day, except July 31 through August 2, which are limited to one hour per day. All work from July 31 through August 8 must be completed remotely, so that period is reserved for ROS, simulation, mathematics, and documentation.

## Phase 1: CAD, ordering, and manufacturing preparation

| Date | Daily goal |
| --- | --- |
| July 19 | Finish CAD revision 1; check joint motion, interference, fastener access, cable paths, and mass properties. |
| July 20 | Complete shoulder and elbow torque calculations; finalize actuators and power requirements. |
| July 21 | Create the bill of materials and order servos, bearings, fasteners, electronics, and power components. |
| July 22 | Produce critical fit-test parts for servo mounts, bearing pockets, and shaft connections. |
| July 23 | Test the fit pieces, correct the CAD, and freeze the final mechanical dimensions. |
| July 24 | Begin manufacturing the base and shoulder components. |
| July 25 | Manufacture the upper-arm and forearm components. |
| July 26 | Manufacture the gripper and remaining brackets. |
| July 27 | Dry-fit the mechanical parts without electronics; check alignment, friction, and fastener access. |
| July 28 | Export simplified CAD meshes and begin the URDF/Xacro robot description. |
| July 29 | Display the arm in RViz and correct mesh scale, coordinate frames, and joint axes. |
| July 30 | Organize physical parts, verify incoming orders, and prepare the ROS workspace for remote work. |

**Milestone:** CAD and manufactured parts are ready, components are ordered, and the robot displays correctly in RViz.

## Phase 2: Remote work with one-hour sessions

| Date | Daily goal |
| --- | --- |
| July 31 | **Remote, 1 hour:** Clean up the ROS workspace, package structure, file names, and launch files. |
| August 1 | **Remote, 1 hour:** Add or correct joint limits, collision geometry, and inertial properties. |
| August 2 | **Remote, 1 hour:** Create the initial `ros2_control` and Joint Trajectory Controller configuration. |

## Phase 3: Remote simulation and coding

| Date | Daily goal |
| --- | --- |
| August 3 | **Remote:** Spawn the arm in Gazebo and stabilize it under gravity. |
| August 4 | **Remote:** Command each simulated joint and fix controller, direction, or joint-limit problems. |
| August 5 | **Remote:** Complete the forward-kinematics math and verify it against ROS TF. |
| August 6 | **Remote:** Complete the inverse-kinematics math for the base, shoulder, and elbow. |
| August 7 | **Remote:** Write the inverse-kinematics Python node with reachability and joint-limit checks. |
| August 8 | **Remote:** Create and test simulated home, approach, pickup, lift, drop, and recovery poses. |

**Milestone:** The simulated arm accepts a target, calculates joint angles, and performs a basic pick-and-place sequence.

## Phase 4: Physical assembly and integration

| Date | Daily goal |
| --- | --- |
| August 9 | Inspect delivered parts and assemble the base and base-rotation joint. |
| August 10 | Assemble the shoulder, elbow, and arm links; check friction manually. |
| August 11 | Assemble the gripper, install the servos, and complete cable routing. |
| August 12 | Wire the power system and test each servo independently at low speed. |
| August 13 | Connect the hardware driver, define zero positions, and calibrate joint directions and offsets. |
| August 14 | Move each physical joint individually and verify that RViz matches the real arm. |
| August 15 | Test slow coordinated movement without a payload; tune speed and safe paths. |

**Milestone:** The physical arm follows ROS commands and matches its state in RViz.

## Phase 5: Pick-and-place, reliability, and final demonstration

| Date | Daily goal |
| --- | --- |
| August 16 | Run the complete pick-and-place sequence without a payload, then test with a lightweight object. |
| August 17 | Run ten repeated trials and fix the most common mechanical or software failure. |
| August 18 | Record the final demonstration and finish the README, CAD screenshots, wiring diagram, and project summary. |

## Completion criteria

- The arm homes consistently.
- The physical joint state is displayed correctly in RViz.
- The arm reaches predefined poses or a validated reachable coordinate.
- The gripper transfers a lightweight object into a predefined bin.
- At least eight of ten repeated pick-and-place attempts succeed.
- The repository contains setup, calibration, launch, and operating instructions.

## Schedule protection

Order components no later than July 21. If time is lost, preserve predefined-pose pick-and-place first and treat arbitrary-coordinate control as the first feature to reduce.

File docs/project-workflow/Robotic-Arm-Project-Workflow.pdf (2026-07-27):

# Robotic Arm Project Workflow

## 3-DOF Desktop Pick-and-Place Arm + 1-DOF Gripper | 3-4 weeks at approximately 3 hours per day (63-84 hours)

# 1. Project Overview

## Project objective

Design, simulate, manufacture, program, and demonstrate a compact robotic arm that can pick up a lightweight object from a known location and place it into one of two predefined bins. The project is deliberately limited to three positioning joints plus a gripper so that the mechanical design, ROS integration, and physical build can all be completed within the available timeframe.

## Degrees of freedom

- Joint 1 - Base yaw: rotates the entire arm left and right.
- Joint 2 - Shoulder pitch: raises and lowers the upper arm.
- Joint 3 - Elbow pitch: extends or retracts the forearm.
- Gripper actuator: opens and closes the jaws; this is normally described separately from the arm's three positioning DOF.
The correct project description is therefore: 3-DOF arm plus a 1-DOF gripper, or four actuated joints in total. The arm can reach an x, y, z position, but it cannot independently control every aspect of end-effector orientation like a 6-DOF industrial arm.

## Target specifications

- Maximum reach: approximately 250-350 mm.
- Payload: approximately 100-200 g, using foam blocks or similarly light objects.
- Structure: 3D-printed, laser-cut, or simple machined links with standard fasteners and bearings.
- Motion: slow, position-controlled, and limited to a safe tabletop workspace.
- Actuation: three position-controlled arm actuators plus one smaller gripper actuator.
- Feedback: measured joint position where available; commanded position may be used as an estimate only for actuators without feedback.
- Control computer: Ubuntu 24.04 with ROS 2 Jazzy.
- Simulation: RViz and Gazebo.
- Primary programming language: Python; C++ is an optional stretch goal.

## Final demonstration

The final system should accept either a predefined target or a simple x, y, z coordinate, calculate the required joint angles, move through a safe approach path, close the gripper, lift the object, move to a bin, release it, and return to the home position.

# 2. System Architecture

## Mechanical system

- Rigid table-mounted base with a rotating platform.
- Separate bearing support at the base so the actuator shaft does not carry the full radial and overturning load.
- Shoulder and elbow links designed around defined joint axes and realistic fastener access.
- Lightweight forearm and gripper to reduce shoulder torque.
- Mechanical hard stops or geometry that prevents damaging over-rotation.
- Cable routing that does not snag throughout the intended workspace.
- Optional extension spring or elastic counterbalance at the shoulder.

## Actuation and electronics

- Prefer serial smart servos with position feedback when budget permits.
- If ordinary hobby servos are used, keep payload and reach conservative and clearly distinguish commanded position from measured position.
- Use a microcontroller as the low-level actuator interface if the actuators cannot connect directly to the ROS computer.
- Provide a separate, correctly rated actuator power supply; do not power the motors from the computer's USB port.
- Include a physical power-disconnect or emergency-stop method.
- Limit software speed, acceleration, and joint range before the first powered test.

## ROS 2 package structure

- mini_arm_description - URDF/Xacro files, CAD meshes, joint limits, collision geometry, and RViz configuration.
- mini_arm_bringup - launch files, controller configuration, parameters, and simulation/hardware selection.
- mini_arm_driver - actuator communication, command output, measured joint-state input, timeouts, and hardware status.
- mini_arm_kinematics - forward kinematics, inverse kinematics, reachability checks, and coordinate transforms.

- mini_arm_tasks - homing, predefined poses, pick-and-place sequences, and recovery behavior.

## Command and feedback flow

- A user or task node provides a target position or named pose.
- The kinematics node verifies that the target is reachable and calculates base, shoulder, and elbow angles.
- A trajectory is generated from the current joint state to the target joint state.
- The controller or driver sends position commands to the physical actuators.
- Actuator feedback is published as sensor_msgs/JointState.
- robot_state_publisher uses the URDF and joint states to publish the link transforms.
- RViz displays the measured or estimated physical configuration of the arm.

# 3. Detailed Four-Week Workflow

## Week 1 - Requirements, calculations, and SolidWorks design

Goal: finish a mechanically credible design before purchasing or manufacturing final components.

### Days 1-2: Requirements and workspace

- Write down maximum reach, payload, object size, desired pickup height, bin locations, and available table area.
- Choose conservative joint limits for the base, shoulder, and elbow.
- Sketch the desired side-view workspace and identify unreachable or unsafe regions.
- Decide whether the arm will be bolted to a base plate or clamped to a table.
- Define a home pose that is stable, compact, and away from hard stops.

### Days 2-3: Torque and actuator sizing

- Create a simple mass estimate for the payload, gripper, forearm, elbow hardware, and upper arm.
- Calculate worst-case static torque with the arm horizontal: torque is approximately gravity multiplied by the sum of each mass times its distance from the joint.
- Apply a safety factor of approximately 1.5-2 to the static torque estimate.
- Size the shoulder actuator first, because it carries the largest combined load.
- Repeat the calculation for the elbow and base.
- Reduce link length or moving mass if the required torque becomes excessive.
- Do not finalize motor mounts until the actuator choice and mounting dimensions are confirmed.

### Days 3-5: Parametric CAD skeleton

- Create a master layout sketch containing the base axis, shoulder axis, elbow axis, tool point, and nominal link lengths.
- Use global variables or equations for link length, joint spacing, bearing size, wall thickness, and fastener diameter.
- Place joint coordinate systems at the intended rotation axes; these will later simplify URDF creation.
- Create simplified actuator and bearing envelope models before designing detailed mounts.
- Test several arm configurations in the assembly and confirm the intended workspace.

### Days 5-7: Detailed mechanical design

- Design the base, upper arm, forearm, actuator brackets, bearing supports, and gripper.
- Use ribs, fillets, shells, and material removal to improve stiffness-to-mass ratio.
- Provide tool access for every nut, screw, and bearing.
- Check for interference across the full joint range.
- Use SolidWorks mass properties to update the torque calculation.
- Create an exploded assembly and at least one manufacturing drawing.
- Freeze the first manufacturable revision at the end of the week.

## Week 2 - URDF, visualization, simulation, and kinematics

Goal: make the exact CAD-based robot move correctly in software before assembling hardware.

### Days 8-9: ROS workspace and robot description

- Create a Git repository and ROS 2 workspace.
- Create the mini_arm_description and mini_arm_bringup packages.
- Export simplified visual meshes from SolidWorks with consistent units and coordinate orientation.
- Use primitive boxes and cylinders for collision geometry wherever possible.
- Write the URDF as Xacro with links for the base, upper arm, forearm, and gripper.
- Define revolute joints, axes, position limits, velocity limits, and effort limits.
- Add inertial values using SolidWorks mass and center-of-mass information.

### Days 10-11: RViz and TF validation

- Launch robot_state_publisher and joint_state_publisher_gui.
- Move each joint separately and confirm that it rotates about the correct axis.
- Inspect the TF tree and verify that link names and parent-child relationships are correct.
- Check that the visual meshes align with the joint frames.
- Correct scale errors, flipped axes, and mesh origins before proceeding.
- Save an RViz configuration showing the robot model, TF frames, and joint state.

### Days 12-14: Simulation and kinematics

- Spawn the robot in Gazebo and verify that it remains stable under gravity.
- Configure position interfaces and a joint trajectory controller.
- Test slow single-joint commands before commanding multiple joints.
- Write a forward-kinematics function that calculates the tool position from the three joint angles.
- Compare the calculated tool position with the TF transform reported by ROS.
- Write an analytic inverse-kinematics solution using base angle plus two-link planar geometry.
- Reject targets outside the reachable workspace and handle both elbow-up and elbow-down solutions.
- Command several safe points in simulation and log the joint states.

## Week 3 - Manufacturing, assembly, and hardware control

Goal: produce a slowly moving physical arm with reliable joint commands and state reporting.

### Days 15-17: Manufacture and assemble

- Manufacture the frozen CAD revision and inspect critical dimensions before full assembly.
- Install bearings and shafts without forcing misaligned parts together.
- Assemble one joint at a time and check friction by hand before installing the actuator.
- Route cables with enough service loop for motion but not enough slack to snag.
- Verify the center of mass and confirm that the unpowered arm cannot fall dangerously.
- Update the CAD assembly to record any fit corrections made during construction.

### Days 18-19: Low-level actuator tests

- Test each actuator individually at low speed and with the link disconnected when possible.
- Confirm direction, zero position, allowable range, current behavior, and feedback.
- Set conservative firmware or actuator limits.
- Create a repeatable mechanical or sensor-based homing procedure.
- Test the emergency-stop or power-disconnect method.
- Do not test coordinated motion until every individual joint behaves correctly.

### Days 20-21: ROS hardware driver

- Create mini_arm_driver and establish communication with the actuators or microcontroller.
- Subscribe to safe joint-position or trajectory commands.
- Publish measured joint positions, velocities when available, and timestamps.
- Implement a command timeout that stops or holds motion if communication is lost.
- Add parameters for joint IDs, directions, zero offsets, and limits.

- Compare physical joint positions with the RViz model.
- Calibrate zero offsets so the physical arm and URDF agree.

## Week 4 - Task automation, testing, and documentation

Goal: turn individual joint control into a repeatable pick-and-place demonstration.

### Days 22-24: Safe poses and motion sequencing

- Define named poses for home, pickup approach, pickup, lift, bin approach, bin drop, and recovery.
- Move between poses at reduced speed while watching for cable and collision problems.
- Approach objects from above or from one consistent direction.
- Always lift the object before rotating the base toward the bin.
- Add pauses or completion checks before closing and opening the gripper.
- Return to the home pose after a successful or aborted task.

### Days 25-26: Pick-and-place task node

- Create mini_arm_tasks with a simple state machine or ROS action.
- Accept a named pickup location, named bin, or validated x, y, z target.
- Check inverse-kinematics success before starting motion.
- Report the active step and any failure reason.
- Allow cancellation and transition to a safe recovery pose.
- Run at least ten repeated simulated cycles before testing the complete physical sequence.

### Days 27-28: Validation and project handoff

- Complete repeated physical pick-and-place trials with lightweight objects.
- Record success rate, positioning error, cycle time, and observed failure modes.
- Capture screenshots of the CAD assembly, RViz model, TF tree, and Gazebo simulation.
- Record a short video showing the physical arm and the corresponding RViz state.
- Write setup, launch, calibration, and operating instructions.
- Document limitations and identify the next mechanical and software improvements.

# 4. Core Engineering and Coding Tasks

## Static torque calculation

For each gravity-loaded joint, estimate the worst-case horizontal holding torque using: torque = g x (payload mass x payload distance + sum of each link/component mass x its center-of-mass distance). Recalculate after obtaining SolidWorks mass properties. The actuator's practical continuous capability, rather than only its advertised stall torque, should exceed the required holding torque with an appropriate safety factor.

## Three-joint inverse kinematics

- Calculate base yaw with atan2(y, x).
- Convert the horizontal target into radial distance from the base axis.
- Solve the shoulder and elbow as a two-link planar arm using the radial distance and target height.
- Clamp numerical values carefully before inverse cosine calculations.
- Reject targets that are too close, too far away, below the table, or outside joint limits.
- Choose one consistent elbow configuration unless there is a reason to switch.
- Compare the inverse solution by passing it back through forward kinematics.

## Trajectory and safety behavior

- Never jump directly between distant joint commands.
- Use timed waypoints or the ROS 2 Joint Trajectory Controller.
- Enforce position, velocity, and acceleration limits in more than one layer where practical.
- Stop or hold position after stale commands.
- Keep the gripper and payload away from the table during base rotation.
- Test every new sequence in simulation before running it on hardware.

# 5. Validation Checklist

## Mechanical

- No interference throughout the software-limited joint range.
- Bearings support external loads rather than relying solely on actuator shafts.
- Fasteners remain accessible and do not loosen during repeated motion.
- Cables remain clear of joints and do not limit motion.
- The arm holds the intended payload without excessive deflection or overheating.

## ROS and software

- The URDF model matches the physical link lengths and joint axes.
- All joint states have correct names, signs, units, and timestamps.
- The TF tree is complete and free of disconnected frames.
- Forward kinematics agrees with the TF end-effector position.
- Inverse kinematics rejects unreachable targets cleanly.
- Simulation and physical hardware use the same high-level command interface.
- Communication loss produces a safe response.

## Demonstration acceptance criteria

- The arm homes repeatably.
- The arm reaches at least three predefined locations.
- The gripper picks up the selected lightweight object.
- The arm transfers the object to one of two bins.
- The arm returns to home without collision.
- At least eight of ten repeated cycles complete successfully.
- The project can be launched and operated using documented commands.

# 6. Scope Protection

## Do not include in the initial version

- Computer vision or object detection.
- A rotating or multi-axis wrist.
- Force or torque control.
- Custom circuit-board design.
- High payloads, long reach, or high-speed motion.
- Complex gearboxes unless they are the main SolidWorks learning objective.
- Autonomous grasp planning for objects in arbitrary orientations.

## Optional stretch goals after the core system works

- Configure MoveIt for collision-aware motion planning.
- Add a wrist-pitch joint, making the arm 4-DOF plus gripper.
- Port the hardware driver or kinematics node from Python to C++.
- Add a camera and AprilTag-based target localization.
- Add a spring counterbalance and compare actuator effort before and after.
- Create a SolidWorks design table for alternate link lengths or actuators.

# 7. Definition of Done

The project is complete when the arm exists as a parametric SolidWorks assembly, a valid ROS 2 URDF/Xacro model, a working Gazebo simulation, and a safe physical prototype. It must publish joint states, display correctly in RViz, accept a validated target or named pose, execute a repeatable pick-and-place sequence, and include sufficient documentation for the system to be rebuilt and operated later.

# 8. Active Project Timeline and Availability Plan

Maximum available time: approximately 87 hours. The schedule protects the remote-only period, limits the first three remote sessions to one hour, and reserves the final ten days for physical assembly and testing.

## Phase 1 - CAD, ordering, and manufacturing preparation

- Jul 19, 2026 - Finish CAD revision 1; check joint motion, interference, fastener access, cable paths, and mass properties.
- Jul 20, 2026 - Complete shoulder and elbow torque calculations; finalize actuators and power requirements.
- Jul 21, 2026 - Create the bill of materials and order servos, bearings, fasteners, electronics, and power components.
- Jul 22, 2026 - Produce critical fit-test parts for servo mounts, bearing pockets, and shaft connections.
- Jul 23, 2026 - Test the fit pieces, correct the CAD, and freeze the final mechanical dimensions.
- Jul 24, 2026 - Begin manufacturing the base and shoulder components.
- Jul 25, 2026 - Manufacture the upper-arm and forearm components.
- Jul 26, 2026 - Manufacture the gripper and remaining brackets.
- Jul 27, 2026 - Dry-fit the mechanical parts without electronics; check alignment, friction, and fastener access.
- Jul 28, 2026 - Export simplified CAD meshes and begin the URDF/Xacro robot description.
- Jul 29, 2026 - Display the arm in RViz and correct mesh scale, coordinate frames, and joint axes.
- Jul 30, 2026 - Organize physical parts, verify incoming orders, and prepare the ROS workspace for remote work.

## Phase 2 - Remote work with one-hour sessions

- Jul 31, 2026 - Remote, 1 hour: clean up the ROS workspace, package structure, file names, and launch files.
- Aug 1, 2026 - Remote, 1 hour: add or correct joint limits, collision geometry, and inertial properties.
- Aug 2, 2026 - Remote, 1 hour: create the initial ros2_control and Joint Trajectory Controller configuration.

## Phase 3 - Remote simulation and coding

- Aug 3, 2026 - Remote: spawn the arm in Gazebo and stabilize it under gravity.

- Aug 4, 2026 - Remote: command each simulated joint and fix controller, direction, or joint-limit problems.
- Aug 5, 2026 - Remote: complete the forward-kinematics math and verify it against ROS TF.
- Aug 6, 2026 - Remote: complete the inverse-kinematics math for the base, shoulder, and elbow.
- Aug 7, 2026 - Remote: write the inverse-kinematics Python node with reachability and joint-limit checks.
- Aug 8, 2026 - Remote: create and test simulated home, approach, pickup, lift, drop, and recovery poses.

## Phase 4 - Physical assembly and integration

- Aug 9, 2026 - Inspect delivered parts and assemble the base and base-rotation joint.
- Aug 10, 2026 - Assemble the shoulder, elbow, and arm links; check friction manually.
- Aug 11, 2026 - Assemble the gripper, install the servos, and complete cable routing.
- Aug 12, 2026 - Wire the power system and test each servo independently at low speed.
- Aug 13, 2026 - Connect the hardware driver, define zero positions, and calibrate joint directions and offsets.
- Aug 14, 2026 - Move each physical joint individually and verify that RViz matches the real arm.
- Aug 15, 2026 - Test slow coordinated movement without a payload; tune speed and safe paths.

## Phase 5 - Pick-and-place, reliability, and final demonstration

- Aug 16, 2026 - Run the complete pick-and-place sequence without a payload, then test with a lightweight object.
- Aug 17, 2026 - Run ten repeated trials and fix the most common mechanical or software failure.
- Aug 18, 2026 - Record the final demonstration and finish the README, CAD screenshots, wiring diagram, and project summary.

## Completion criteria

- The arm homes consistently.
- The physical joint state is displayed correctly in RViz.
- The arm reaches predefined poses or a validated reachable coordinate.
- The gripper transfers a lightweight object into a predefined bin.
- At least eight of ten repeated pick-and-place attempts succeed.
- The repository contains setup, calibration, launch, and operating instructions.

Schedule protection: order components no later than the ordering task above. If time is lost, preserve predefined-pose pick-and-place first and treat arbitrary-coordinate control as the first feature to reduce.

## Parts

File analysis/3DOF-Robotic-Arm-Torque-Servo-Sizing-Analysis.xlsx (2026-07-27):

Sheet: Design Summary
3DOF Robotic Arm — Torque & Servo Sizing Analysis
Formula-driven engineering summary for the worst-case horizontal pose with a 10 g foam-ball payload and a 2.0× design safety factor.
Joint Sizing Results
Joint | Static torque (kgf·cm) | Required design torque (kgf·cm) | MG996R stall torque (kgf·cm) | Design utilization | Margin ratio | Status
Elbow | 1.94 | 3.88 | 11.00 | 35.3% | 2.83 | PASS
Shoulder | 3.82 | 7.65 | 11.00 | 69.5% | 1.44 | PASS
Engineering Interpretation
Limiting joint | Shoulder
Result | Shoulder design utilization is 69.5% with a 1.44x stall/design margin.
Servo conclusion | Both joints pass the simplified stall-torque comparison for a 10 g payload at 6.0 V.
Risk / limitation | The shoulder has less reserve. MG996R torque is an advertised stall value, not a continuous holding rating.
Recommendation | Use a regulated 6 V supply, bench-test the arm horizontally, monitor heating/jitter, and add a counterbalance or stronger shoulder servo if needed.
Validation Before Final Hardware Sign-Off
1 | Replace solid-PLA CAD masses with slicer-estimated masses after infill, wall count, and supports are chosen.
2 | Weigh the actual foam ball and update the payload input.
3 | Confirm the servo body mounting side for each joint so only truly moving mass is included.
4 | Bench-test holding and slow motion in the worst-case horizontal pose using a current-limited 6 V supply.
5 | Record measured current, position error, heating, and any deflection; revise the shoulder actuator if reserve is insufficient.

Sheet: Inputs & Sources
3DOF Robotic Arm — Engineering Inputs & Sources
Yellow cells are editable inputs. Blue cells are formulas. Measurements are from SolidWorks Mass Properties and the exported STEP assembly.
Global Assumptions and Servo Data
Parameter | Value | Units | Basis / source
Gravity | 9.81 | m/s² | Standard gravitational acceleration
Design safety factor | 2.00 | × | Applied to total static joint torque
Payload mass | 10.00 | g | Conservative assumption for a foam ball ≤ 2 in diameter
kgf·cm to N·m conversion | 0.0980665 | N·m per kgf·cm | 1 kgf·cm = 0.0980665 N·m
PLA density used in CAD | 1240 | kg/m³ | Solid PLA model; replace with slicer mass after infill is chosen
Selected servo supply voltage | 6.00 | V | Planned regulated servo supply
MG996R stall torque @ 4.8 V | 9.40 | kgf·cm | TowerPro official MG996R specification
MG996R stall torque @ 6.0 V | 11.00 | kgf·cm | TowerPro official MG996R specification
Selected MG996R stall torque | 11.00 | kgf·cm | Formula selects the rating for the chosen supply voltage
Joint Inputs from SolidWorks and STEP Geometry
Joint | Moving mass (g) | COM X (mm) | COM Y (mm) | COM Z (mm) | COM radius (mm) | Payload radius (mm) | Measurement basis
Elbow | 217.60 | 481.27 | 724.78 | 1443.91 | 76.46 | 277.20 | Elbow-only component selection; payload radius to jaw-tip center
Shoulder | 297.31 | 512.58 | 740.98 | 1432.66 | 116.65 | 353.30 | Link 1 plus elbow-moving assembly; payload radius to jaw-tip center
Documentation, Provenance, and Engineering Limitations
Item | Source / value |  | Why it matters |  |  | URL or file
SolidWorks mass properties | 2025 Design Help |  | Documents selected-component mass and center-of-mass reporting |  |  | https://help.solidworks.com/2025/English/SolidWorks/sldworks/HIDD_MASSPROPERTY_TEXT_DLG.htm
MG996R specification | 55 g; 9.4 kgf·cm @ 4.8 V; 11 kgf·cm @ 6.0 V |  | Servo sizing comparison uses the manufacturer stall rating |  |  | https://towerpro.com.tw/product/mg996r/
CAD assembly | RobotArmAssembly.STEP |  | Joint axes and conservative jaw-tip payload radii |  |  | Exported from SolidWorks 2025 on 2026-07-22
Printed-part mass caveat | CAD currently uses solid PLA density |  | Slicer estimates should replace CAD masses after infill, walls, and supports are finalized |  |  | Validation item
Servo torque caveat | Advertised torque is stall torque, not continuous-duty torque |  | Bench testing and thermal monitoring are required before sustained holding |  |  | Validation item
Payload assumption | 10 g foam ball, ≤ 2 in diameter |  | Editable assumption; weigh the actual ball before final validation |  |  | User-defined design target

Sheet: Torque Calculations
Joint Torque Calculations
Worst-case static pose: arm extended horizontally. Every derived number below is formula-driven from the Inputs & Sources tab.
1. Static Torque Components
Joint | Moving mass (g) | Mass (kg) | COM radius (mm) | COM radius (m) | Arm torque (N·m) | Payload (g) | Payload (kg) | Payload radius (mm) | Payload torque (N·m)
Elbow | 217.60 | 0.21760 | 76.46 | 0.07646 | 0.163 | 10.00 | 0.01000 | 277.20 | 0.027
Shoulder | 297.31 | 0.29731 | 116.65 | 0.11665 | 0.340 | 10.00 | 0.01000 | 353.30 | 0.035
2. Safety Factor and Servo Capacity Check
Joint | Total static torque (N·m) | Static torque (kgf·cm) | Safety factor | Required design torque (N·m) | Required design torque (kgf·cm) | MG996R stall torque (kgf·cm) | Stall/design margin ratio | Design utilization | Status
Elbow | 0.190 | 1.94 | 2.0 | 0.381 | 3.88 | 11.00 | 2.83 | 35.3% | PASS
Shoulder | 0.375 | 3.82 | 2.0 | 0.750 | 7.65 | 11.00 | 1.44 | 69.5% | PASS
Formula Audit Trail
Calculation |  | Formula |  |  |  | Interpretation
Arm gravity torque |  | τ_arm = (m_arm / 1000) × g × (r_COM / 1000) |  |  |  | Moving-link mass acting at the selected components’ center of mass
Payload gravity torque |  | τ_payload = (m_payload / 1000) × g × (r_payload / 1000) |  |  |  | Ball treated as a point mass at the conservative jaw-tip center
Required design torque |  | τ_design = (τ_arm + τ_payload) × safety factor |  |  |  | Safety factor is applied after combining arm and payload torque
Capacity check |  | Margin ratio = advertised stall torque / required design torque |  |  |  | A ratio ≥ 1 passes the simplified stall-torque check; bench validation is still required

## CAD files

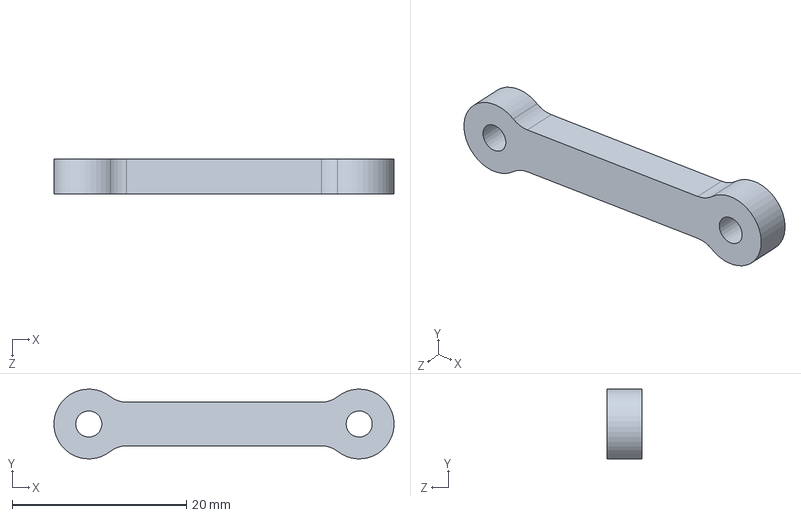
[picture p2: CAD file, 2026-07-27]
cad/all-links/Robot-Arm-Gripper-Connecting-Link.SLDPRT
39.0 x 7.99 x 4.00 mm

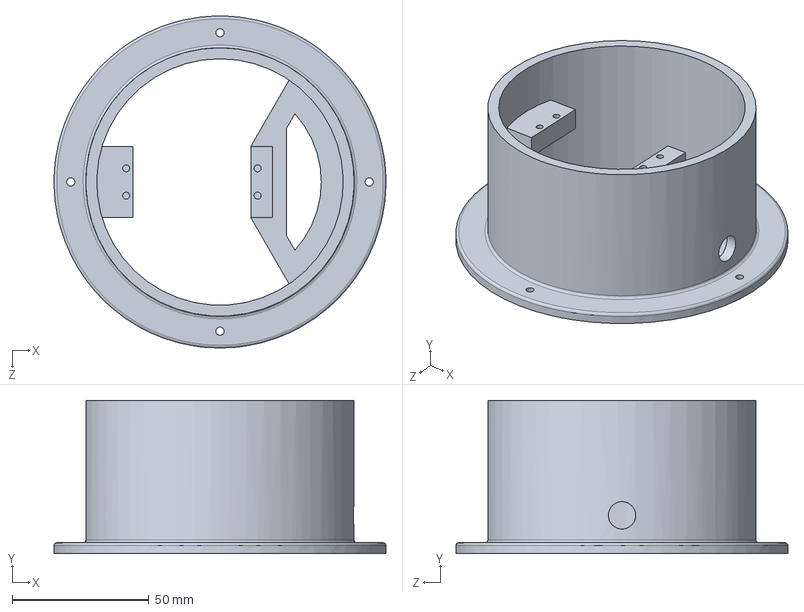
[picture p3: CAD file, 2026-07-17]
cad/base/Robot-Arm-Base-v1.SLDPRT
121.2 x 56.0 x 121.2 mm

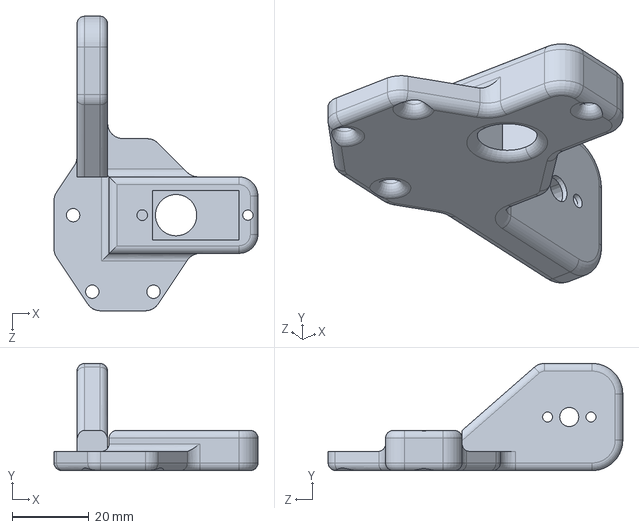
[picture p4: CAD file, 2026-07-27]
cad/gripper/Robot-Arm-Gripper-First-Link.SLDPRT
53.3 x 28.0 x 77.0 mm

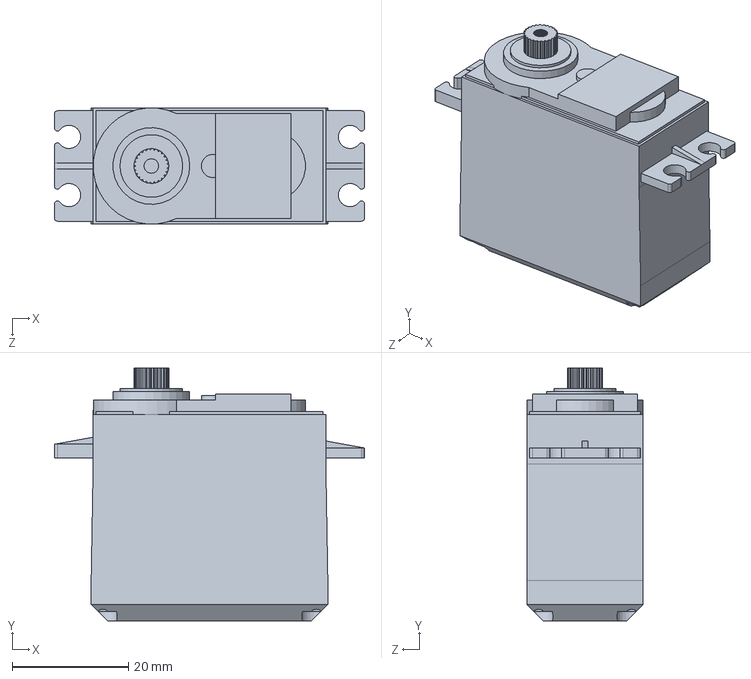
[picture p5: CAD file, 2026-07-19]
cad/servo/MG996R_servo.SLDPRT
53.3 x 43.5 x 20.0 mm

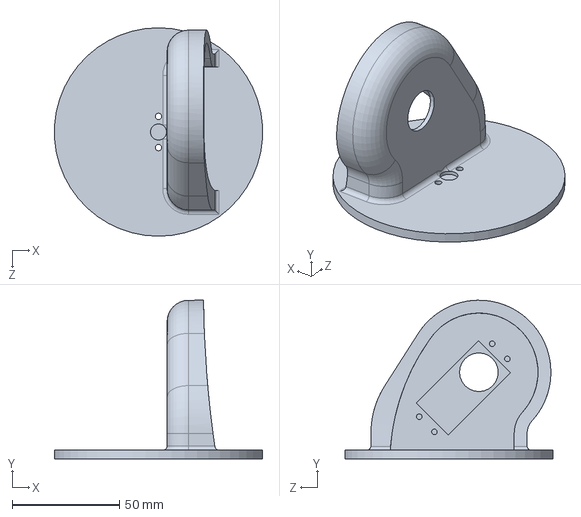
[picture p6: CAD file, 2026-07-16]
cad/waist/Robot-Arm-Waist-v1.SLDPRT
96.8 x 73.8 x 97.0 mm

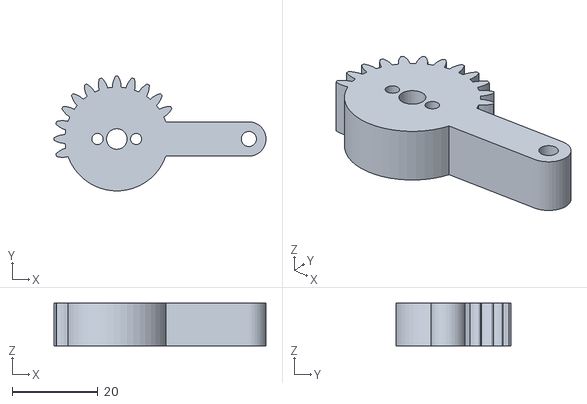
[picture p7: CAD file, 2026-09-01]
ros2_ws/src/robot_arm_description/STL/gripper_gear.stl
49.4 x 26.7 x 10.0

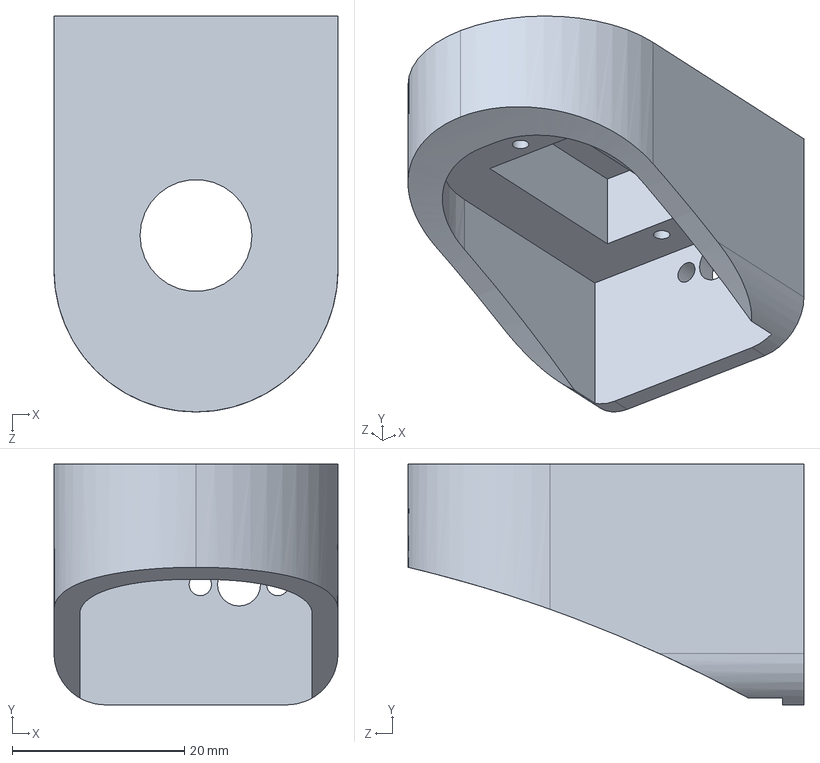
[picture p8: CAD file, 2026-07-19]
cad/all-links/Robot-Arm-Link-3.SLDPRT
33.0 x 28.0 x 46.0 mm

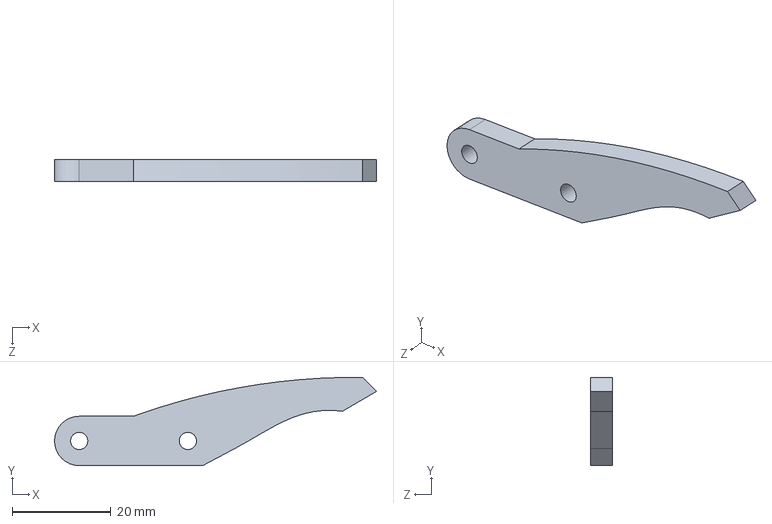
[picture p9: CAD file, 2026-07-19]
cad/gripper/Robot-Arm-Gripper-Link-1.SLDPRT
65.2 x 17.9 x 4.50 mm

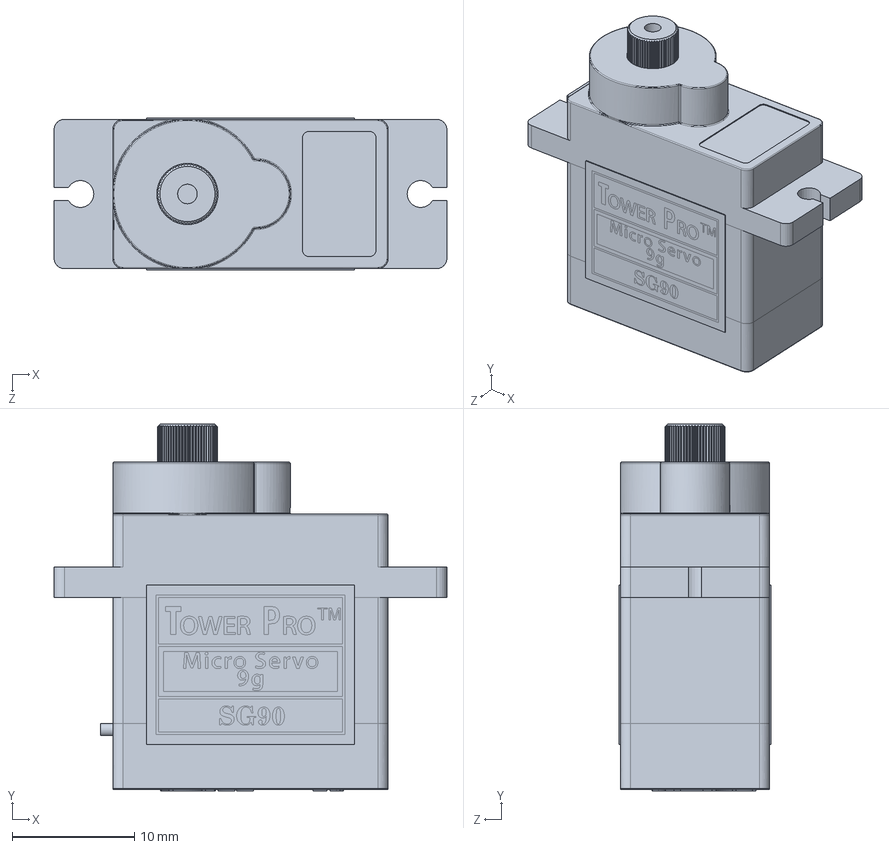
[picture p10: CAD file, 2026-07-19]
cad/servo/SG90 - Micro Servo 9g - Tower Pro.1.SLDPRT
32.1 x 30.0 x 12.4 mm

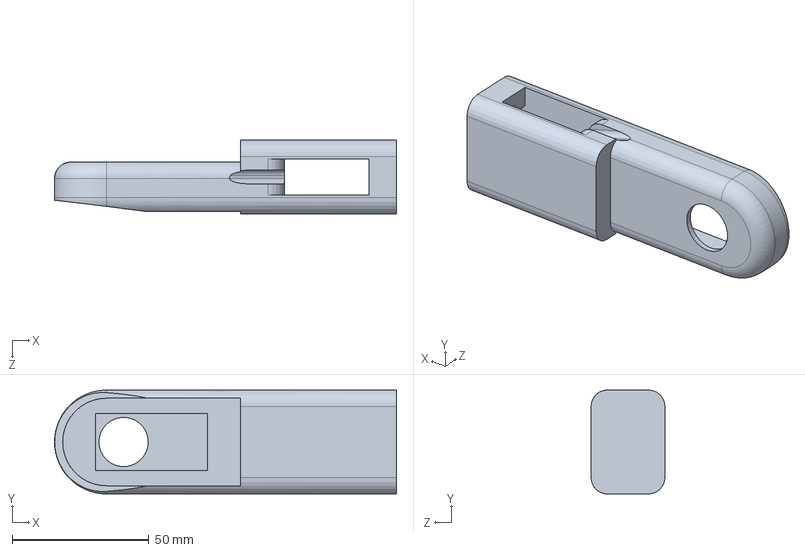
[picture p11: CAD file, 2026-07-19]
cad/all-links/Robot-Arm-Link-2.SLDPRT
125.0 x 38.0 x 27.0 mm

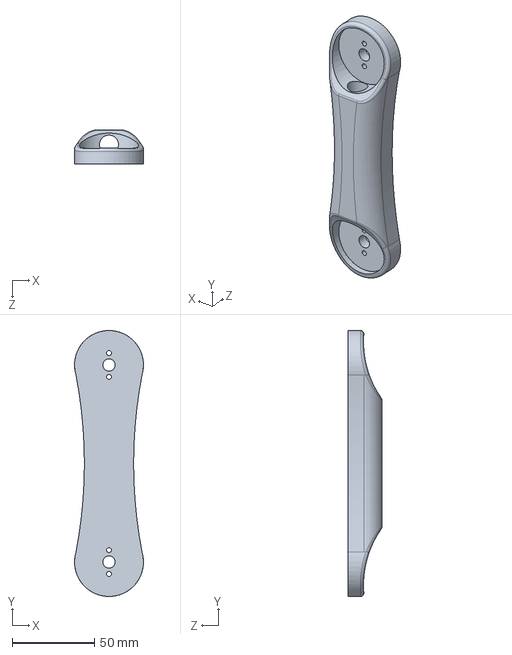
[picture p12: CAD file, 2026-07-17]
cad/all-links/Robot-Arm-Link-1.SLDPRT
42.0 x 162.0 x 21.0 mm

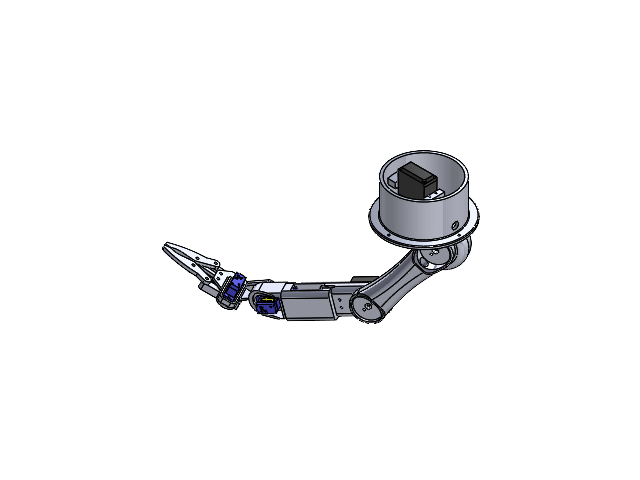
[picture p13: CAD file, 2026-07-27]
cad/assembly/Robot-Arm-Final-Assembly.SLDASM
RoboticArmBase#1
RobotArmWaist#1
MG996R_servo x 3
lin#1
link#2
SG90 - Micro Servo 9g - Tower Pro.1 x 3
gripperFirstLinkRobotArm
gearRobotArm x 2
gripperConnectingLinkRobotArm x 2
gripperLinkRobotArm#1 x 2
link#3RoboticArm

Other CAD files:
ros2_ws/src/robot_arm_description/STL/gripper_base.stl
cad/gripper/gearRobotArm.SLDPRT
ros2_ws/src/robot_arm_description/STL/wrist_link.stl
ros2_ws/src/robot_arm_description/STL/gripper_connecting_link.stl
ros2_ws/src/robot_arm_description/STL/gripper_finger.stl
ros2_ws/src/robot_arm_description/STL/forearm_link.stl
ros2_ws/src/robot_arm_description/STL/base_link.stl
ros2_ws/src/robot_arm_description/STL/upper_arm_link.stl
ros2_ws/src/robot_arm_description/STL/waist_link.stl

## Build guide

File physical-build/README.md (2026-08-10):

# Physical Build: Parts List and Purchase Tracker

This page documents the planned hardware for the 3-DOF robotic arm and the engineering reasoning behind each selection. Exact vendors, part numbers, prices, and purchase status should be updated from receipts as parts are ordered and tested.

## 1. Design basis

- Motion: base yaw, shoulder pitch, elbow pitch, and an actuated gripper.
- Target object: a foam ball up to approximately 2 inches in diameter.
- Calculated shoulder requirement: **7.65 kgf-cm**, including a 2x safety factor.
- Calculated elbow requirement: **3.88 kgf-cm**, including a 2x safety factor.
- The shoulder actuator receives the largest margin because it carries the downstream arm, gripper, and payload.

## 2. Actuators

| Joint | Planned actuator | Quantity | Selection basis | Status |
| --- | --- | ---: | --- | --- |
| Base yaw | MG996R metal-gear servo | 1 | Current CAD selection; adequate for low-speed rotation when the base is supported by a bearing | Planned |
| Shoulder pitch | 20–25 kgf-cm, 6 V digital metal-gear servo | 1 | Provides useful margin above the calculated 7.65 kgf-cm requirement | Planned |
| Elbow pitch | MG996R metal-gear servo | 1 | Rated torque is above the calculated 3.88 kgf-cm requirement | Planned |
| Gripper | MG90S preferred; SG90 acceptable for a light foam ball | 1 | Small, lightweight actuator appropriate for the low gripper load | Planned |
| Spare | Match the most failure-prone arm servo | 1 optional | Reduces downtime during testing | Optional |

Servo stall torque is not a continuous operating rating. Final acceptance testing will check current draw, temperature, backlash, joint friction, and the measured mass of the printed assembly.

## 3. Control electronics

| Component | Quantity | Purpose | Status |
| --- | ---: | --- | --- |
| ESP32 development board | 1 | Runs high-level servo commands and communicates with the computer/ROS 2 system | Planned |
| PCA9685 16-channel PWM driver | 1 | Generates stable PWM signals for all servos over I2C | Planned |
| USB data cable for ESP32 | 1 | Programming, debugging, and serial communication | Planned |
| 1,000 µF capacitor rated for at least 10 V | 1 | Reduces voltage dips near the servo power input | Planned |

The ESP32 provides control signals only. The servos use a separate high-current 6 V power rail, with all grounds connected together.

## 4. Bench power and protection

| Component | Recommended specification | Quantity | Status |
| --- | --- | ---: | --- |
| Regulated DC supply | 6 V, 10 A | 1 | Planned |
| Inline fuse and holder | 10 A | 1 | Planned |
| Master power switch | Rated above expected DC current | 1 | Planned |
| Power distribution block or terminal strip | At least 5 servo/electronics branches | 1 | Planned |

Do not power the arm servos through the ESP32, USB port, PCA9685 logic pin, or a solderless breadboard. High-current servo power should use dedicated wiring and distribution hardware.

## 5. Optional mobile power

| Component | Recommended specification | Quantity | Status |
| --- | --- | ---: | --- |
| Battery | 2S, 7.4 V, 2,200–3,000 mAh LiPo | 1 | Optional |
| UBEC | Regulated 6 V, 10 A output | 1 | Optional |
| Balance charger | Compatible with 2S LiPo batteries | 1 | Optional |
| LiPo safety bag | Sized for the selected battery | 1 | Optional |
| Low-voltage alarm | 2S-compatible | 1 | Optional |
| Battery connector | XT60 pair or selected equivalent | 1 pair | Optional |

Never connect a raw 2S LiPo directly to standard MG996R servos. The UBEC must regulate the battery voltage to the servo rail voltage.

## 6. Wiring and connectors

| Item | Recommended size/type | Estimated quantity | Use |
| --- | --- | ---: | --- |
| Main power wire | 18 AWG stranded | 2–3 m | Supply, fuse, switch, and distribution wiring |
| Servo branch wire | 20–22 AWG stranded | 3–5 m | Individual servo power branches |
| Signal wire | 24–26 AWG stranded | 3–5 m | PWM and I2C signals |
| Servo extension leads | 3-pin, suitable lengths | 4–6 | Removable servo connections |
| Connectors | Ferrules, JST-style plugs, or locking equivalents | Assortment | Serviceable electrical connections |
| Heat-shrink tubing | Assorted diameters | 1 kit | Insulation and strain relief |
| Cable ties or braided sleeve | Small assortment | 1 kit | Cable routing and protection |

All servo grounds, the PCA9685 ground, the ESP32 ground, and the power-supply ground must share a common reference.

## 7. Mechanical hardware

| Item | Suggested starting point | Purpose | Status |
| --- | --- | --- | --- |
| M3 screw assortment | M3 x 6, 8, 10, 12, 16, and 20 mm | Printed-part and electronics mounting | Planned |
| M3 washers and nyloc nuts | Matching assortment | Load spreading and vibration resistance | Planned |
| M3 heat-set inserts | Sized for the printed wall thickness | Reusable threads in printed parts | Planned |
| M2 screw assortment | Verify against the selected micro servo | Gripper-servo mounting | Planned |
| M4/M5 shoulder and elbow hardware | Measure CAD holes before ordering | Structural joint pivots | To verify |
| Spacers or standoffs | Assorted M3 sizes | Alignment and electronics mounting | Planned |
| Joint bearings or bushings | Match final shaft diameters | Carry radial joint loads | To verify |
| Base thrust or Lazy Susan bearing | Match the base geometry | Supports the rotating arm above the base servo | To verify |

The servo output shaft should transmit torque, but bearings or bushings should support the arm's structural loads whenever possible.

## 8. Electrical architecture

```text
6 V supply or regulated UBEC
  -> inline fuse
  -> master switch
  -> power distribution
       -> base, shoulder, elbow, and gripper servos
       -> PCA9685 servo-power input

Computer USB -> ESP32 -> I2C -> PCA9685 -> servo signal lines
All grounds connected together
```

## 9. Camera plan

- Initial vision testing will use a phone secured on a fixed tripod or stand and streamed to the computer over Wi-Fi.
- Keeping the phone off the arm avoids adding mass and torque at the shoulder and elbow.
- A dedicated USB camera can be added later if repeatable calibration, lower latency, or fully integrated ROS 2 image topics become necessary.

## 10. Bring-up and verification sequence

- [ ] Set the regulated supply to 6.0 V before connecting servos.
- [ ] Check the power rail for shorts with a multimeter.
- [ ] Confirm the common ground between the controller and servo rail.
- [ ] Install the fuse and verify the master switch.
- [ ] Test one unloaded servo from the PCA9685.
- [ ] Test each joint individually with no payload.
- [ ] Record current draw, servo temperature, range of motion, and mechanical interference.
- [ ] Test the assembled arm with progressively larger loads up to the target foam ball.

## 11. Engineering skills demonstrated

- Converted SolidWorks mass properties and moment arms into torque requirements with a safety factor.
- Selected actuators by joint load instead of using one servo size everywhere.
- Separated logic power from the high-current servo rail and designed a common-ground PWM architecture.
- Added current protection, voltage regulation, strain relief, and staged test procedures.
- Chose a phone-based camera for early experiments to avoid unnecessary mass and cost.

## 12. Purchase record

Update this table from order confirmations and receipts so the repository distinguishes planned components from hardware actually purchased.

| Item | Manufacturer / model | Vendor | Quantity | Unit price | Order date | Status | Test notes |
| --- | --- | --- | ---: | ---: | --- | --- | --- |
|  |  |  |  |  |  |  |  |
|  |  |  |  |  |  |  |  |
|  |  |  |  |  |  |  |  |

Suggested status values: **Planned**, **Ordered**, **Received**, **Tested**, and **Installed**.

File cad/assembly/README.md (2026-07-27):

# Final Robot Arm Assembly

[`Robot-Arm-Final-Assembly.SLDASM`](Robot-Arm-Final-Assembly.SLDASM) is the final native SolidWorks assembly. Its component models are organized by subsystem in the parent [`cad/`](../) directory.

## Verify Component References

SolidWorks assembly documents reference external part and subassembly files. Before distributing the assembly as a portable release:

1. Open the original assembly in SolidWorks.
2. Select **File > Find References** and enable **Include broken references**. Any entry marked **File not found** identifies a missing component.
3. Select **File > Pack and Go** and save all related files into one folder or ZIP archive.

The repository uses descriptive filenames and subsystem folders, which may differ from paths saved inside the original assembly. A Pack and Go package is the safest way to preserve every dependency for another SolidWorks user.

See the official SolidWorks documentation for [Find References](https://help.solidworks.com/2024/English/solidworks/sldworks/HIDD_FINDREFERENCES_HELP.htm) and [Pack and Go](https://help.solidworks.com/2025/english/SolidWorks/Sldworks/r_pack_go_db.htm).

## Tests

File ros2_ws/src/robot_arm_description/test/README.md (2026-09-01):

# Model validation

`validate_model.py` statically validates the committed URDF/Xacro model and meshes. It uses only the
Python standard library — no ROS, no numpy — so it runs on the development Mac and inside the Ubuntu
VM alike.

```bash
python3 ros2_ws/src/robot_arm_description/test/validate_model.py
```

Exit code is 0 when every check passes and 1 otherwise, so it can be wired into CI or a pre-commit
hook.

## What it checks

Every assertion is recomputed from the real project files. The script deliberately avoids
re-stating constants that the Xacro already contains.

| Group | Checks |
| --- | --- |
| Xacro / XML | Every `${property}` expands; the expanded document parses |
| Tree | One root link, root is `base_link`, no cycles, no orphans, no link with two parent joints, no dangling parent/child references |
| Joints | All seven required joints exist with the expected type; exactly five non-mimic controls, in order |
| Mimic | Exactly one mimic joint; its target exists, is a real control, has a finite non-zero multiplier, and its own limits cover the mimicked range |
| Limits | Every non-fixed joint declares finite, correctly ordered limits that contain zero, and a non-degenerate axis |
| Meshes | Every `package://` reference resolves on disk and is a structurally valid binary STL (header triangle count matches file length); the gear, connector, and finger are each referenced exactly twice |
| Gripper kinematics | Reads `gripper_finger.stl`, finds the fingertip, and recomputes jaw separation through the actual joint transforms: closed at zero, opening with positive rotation, monotonic across the commanded range |
| Hygiene | No `build/`, `install/`, `log/`, `__pycache__`, `.pyc`, or `.DS_Store` files tracked by git |

## Runtime validation in the Ubuntu VM

The script cannot test ROS behaviour. Run these in the VM — see
[`docs/VM_HANDOFF.md`](../../../../docs/VM_HANDOFF.md) for the full procedure.

Expand the Xacro and validate the URDF tree:

```bash
ros2 run xacro xacro ~/robot_arm_ws/src/robot_arm_description/urdf/robot_arm.urdf.xacro -o /tmp/robot_arm.urdf && check_urdf /tmp/robot_arm.urdf
```

`check_urdf` should report `base_link` as the root and list the ten links.

Build the package:

```bash
cd ~/robot_arm_ws && colcon build --symlink-install --packages-select robot_arm_description --cmake-clean-cache
```

Launch the visualization:

```bash
LIBGL_ALWAYS_SOFTWARE=1 MESA_LOADER_DRIVER_OVERRIDE=llvmpipe QT_X11_NO_MITSHM=1 ros2 launch robot_arm_description display.launch.py
```

Confirm the transform chain reaches the moving gripper side:

```bash
ros2 run tf2_ros tf2_echo base_link left_finger_link
```

Confirm the joint states, and that all three mimic joints track `gripper_joint`:

```bash
ros2 topic echo /joint_states
```

Confirm exactly one publisher is driving the sliders:

```bash
ros2 topic info /joint_states --verbose
```

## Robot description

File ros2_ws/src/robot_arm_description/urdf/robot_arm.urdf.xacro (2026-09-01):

<?xml version="1.0"?>
<robot xmlns:xacro="http://www.ros.org/wiki/xacro" name="robot_arm">
  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
  <xacro:property name="upper_arm_length" value="0.12"/>

  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
  <xacro:property name="gripper_open" value="0.75"/>

  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
  <xacro:property name="pla_density" value="1240.0"/>

  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

  <link name="base_link">
    <inertial>
      <origin xyz="0.00107986407 -6.18358027e-07 0.0221277793" rpy="0 0 0"/>
      <mass value="${9.47078684e-05 * pla_density}"/>
      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
    </inertial>


    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
  </link>

  <link name="waist_link">
    <inertial>
      <origin xyz="-0.00467023461 0.00793675396 0.0231640523" rpy="0 0 0"/>
      <mass value="${8.35641672e-05 * pla_density}"/>
      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
    </inertial>


    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
  </link>

  <joint name="base_yaw_joint" type="revolute">
    <parent link="base_link"/>
    <child link="waist_link"/>
    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
    <origin xyz="0 0 0.056" rpy="0 0 0"/>
    <axis xyz="0 0 1"/>
    <limit lower="-3.1416" upper="3.1416" effort="10.0" velocity="1.0"/>
  </joint>

  <link name="upper_arm_link">
    <inertial>
      <origin xyz="0.0599999261 0.00268461785 5.18655088e-07" rpy="0 0 0"/>
      <mass value="${6.43360473e-05 * pla_density}"/>
      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
    </inertial>


    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
  </link>

  <joint name="shoulder_joint" type="revolute">
    <parent link="waist_link"/>
    <child link="upper_arm_link"/>
    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
    <origin xyz="-0.01391 -0.0065 0.04028" rpy="3.1416 -1.503064 3.1416"/>
    <axis xyz="0 1 0"/>
    <limit lower="-1.5708" upper="1.5708" effort="10.0" velocity="1.0"/>
  </joint>

  <link name="forearm_link">
    <inertial>
      <origin xyz="0.0160694724 0.0163146104 -0.0445323533" rpy="0 0 0"/>
      <mass value="${5.72611052e-05 * pla_density}"/>
      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
    </inertial>


    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
  </link>

  <joint name="elbow_joint" type="revolute">
    <parent link="upper_arm_link"/>
    <child link="forearm_link"/>
    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
    <origin xyz="${upper_arm_length} 0 0" rpy="0 0 0"/>
    <axis xyz="0 1 0"/>
    <limit lower="-2.0944" upper="2.0944" effort="10.0" velocity="1.0"/>
  </joint>

  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
  <link name="wrist_link">
    <inertial>
      <origin xyz="-2.42085612e-05 0.00594423645 0.0195846505" rpy="0 0 0"/>
      <mass value="${1.56507039e-05 * pla_density}"/>
      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
    </inertial>

    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
  </link>

  <joint name="wrist_roll_joint" type="revolute">
    <parent link="forearm_link"/>
    <child link="wrist_link"/>
    <origin xyz="0.033726552 0.016000000 -0.093875834" rpy="-3.141592654 0.347914624 -3.141592654"/>
    <axis xyz="0 0 1"/>
    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
    <limit lower="-3.1416" upper="3.1416" effort="5.0" velocity="1.0"/>
  </joint>

  <link name="gripper_base_link">
    <inertial>
      <origin xyz="0.00318308193 0.00755952549 -0.0130397199" rpy="0 0 0"/>
      <mass value="${1.60468383e-05 * pla_density}"/>
      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
    </inertial>

    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
  </link>

  <joint name="wrist_pitch_joint" type="revolute">
    <parent link="wrist_link"/>
    <child link="gripper_base_link"/>
    <origin xyz="0.034300380 0.013001510 0.047026012" rpy="-1.363351778 0 -1.570796327"/>
    <axis xyz="1 0 0"/>
    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
    <limit lower="-1.5708" upper="1.5708" effort="5.0" velocity="1.0"/>
  </joint>

  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
  <link name="left_gear_link">
    <inertial>
      <origin xyz="0.00893746607 0.00149975966 0.00466186796" rpy="0 0 0"/>
      <mass value="${7.25980177e-06 * pla_density}"/>
      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
    </inertial>

    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
  </link>

  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
  <joint name="gripper_joint" type="revolute">
    <parent link="gripper_base_link"/>
    <child link="left_gear_link"/>
    <origin xyz="0.016900000 0 0" rpy="3.141592654 -1.570796327 -1.570796327"/>
    <axis xyz="0 0 1"/>
    <limit lower="0.0" upper="${gripper_open}" effort="5.0" velocity="1.0"/>
  </joint>

  <link name="left_finger_link">
    <inertial>
      <origin xyz="0.0141037757 0.00359027469 0.00224999852" rpy="0 0 0"/>
      <mass value="${2.69867188e-06 * pla_density}"/>
      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
    </inertial>

    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
  </link>

  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
  <joint name="left_finger_joint" type="revolute">
    <parent link="left_gear_link"/>
    <child link="left_finger_link"/>
    <origin xyz="0.040876871 0.004294937 0" rpy="-3.141592654 0 0.401119022"/>
    <axis xyz="0 0 1"/>
    <limit lower="0.0" upper="${gripper_open}" effort="5.0" velocity="1.0"/>
    <mimic joint="gripper_joint" multiplier="1.0" offset="0.0"/>
  </joint>

  <link name="right_gear_link">
    <inertial>
      <origin xyz="0.00880575529 0.00172047236 0.00533813509" rpy="0 0 0"/>
      <mass value="${7.25980177e-06 * pla_density}"/>
      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
    </inertial>

    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
  </link>

  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
  <joint name="right_gripper_joint" type="revolute">
    <parent link="gripper_base_link"/>
    <child link="right_gear_link"/>
    <origin xyz="-0.009999717 -0.010000000 0" rpy="1.570796327 -1.444499427 3.141592654"/>
    <axis xyz="0 0 1"/>
    <limit lower="0.0" upper="${gripper_open}" effort="5.0" velocity="1.0"/>
    <mimic joint="gripper_joint" multiplier="1.0" offset="0.0"/>
  </joint>

  <link name="right_finger_link">
    <inertial>
      <origin xyz="0.0141037757 0.00359027469 0.00224999852" rpy="0 0 0"/>
      <mass value="${2.69867188e-06 * pla_density}"/>
      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
    </inertial>

    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
  </link>

  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
  <joint name="right_finger_joint" type="revolute">
    <parent link="right_gear_link"/>
    <child link="right_finger_link"/>
    <origin xyz="0.040292060 0.005472576 0.014500000" rpy="-3.141592654 0 0.520722397"/>
    <axis xyz="0 0 1"/>
    <limit lower="0.0" upper="${gripper_open}" effort="5.0" velocity="1.0"/>
    <mimic joint="gripper_joint" multiplier="1.0" offset="0.0"/>
  </joint>

</robot>

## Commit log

2026-07-16 Add robotic arm project workflow
2026-07-16 Organize project documentation and CAD files
    [Robot-Arm-Base-v1.SLDPRT]
2026-07-16 Upload updated robot arm base model
    [Robot-Arm-Base-v1.SLDPRT]
2026-07-17 Separate robot arm base and waist models
    [Robot-Arm-Base-v1.SLDPRT, Robot-Arm-Waist-v1.SLDPRT]
2026-07-17 Upload robot arm link model
    [Robot-Arm-Link-v1.SLDPRT]
2026-07-19 Upload second robot arm link
    [Robot-Arm-Link-1.SLDPRT, Robot-Arm-Link-2.SLDPRT]
2026-07-19 Upload third robot arm link
    [Robot-Arm-Link-3.SLDPRT]
2026-07-19 Upload servo CAD models
    [MG996R_servo.SLDPRT, SG90 - Micro Servo 9g - Tower Pro.1.SLDPRT]
2026-07-19 Upload robot arm gear model
    [gearRobotArm.SLDPRT]
2026-07-19 Upload robot arm gripper link
    [Robot-Arm-Gripper-Link-1.SLDPRT]
2026-07-19 Organize gear and all-links CAD models
    [Robot-Arm-Gripper-Connecting-Link.SLDPRT, Robot-Arm-Gripper-Link-1.SLDPRT, Robot-Arm-Link-1.SLDPRT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]
2026-07-19 Organize gripper CAD models
    [Robot-Arm-Gripper-First-Link.SLDPRT, Robot-Arm-Gripper-Link-1.SLDPRT, gearRobotArm.SLDPRT]
2026-07-21 Upload final robot arm assembly
    [Robot-Arm-Final-Assembly.SLDASM]
2026-07-21 Mark CAD milestone complete
2026-07-26 Add torque and servo sizing analysis
    [3DOF-Robotic-Arm-Torque-Servo-Sizing-Analysis.xlsx]
2026-07-27 Add ROS 2 progress and robot description
    [robot_arm.urdf.xacro]
2026-07-27 Add validated base link STL
    [base_link.stl]
2026-07-27 Use CAD mesh for ROS base link
    [robot_arm.urdf.xacro]
2026-07-27 Add validated waist link STL
    [waist_link.stl]
2026-07-27 Add CAD upper-arm mesh to ROS model
    [robot_arm.urdf.xacro, upper_arm_link.stl]
2026-07-27 Fix upper-arm orientation in ROS model
    [robot_arm.urdf.xacro]
2026-07-27 Align waist mesh with CAD base
    [robot_arm.urdf.xacro]
2026-07-28 Correct waist and upper-arm mesh axes
    [robot_arm.urdf.xacro]
2026-08-10 Document physical build parts and power plan
2026-08-13 Add STEP-aligned forearm ROS mesh
    [forearm_link.stl, robot_arm.urdf.xacro]
2026-09-01 Correct forearm STL origin offset
    [robot_arm.urdf.xacro]
2026-09-01 Add complete wrist and gripper CAD assembly
    [gripper_base.stl, gripper_connecting_link.stl, gripper_finger.stl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]
2026-09-01 Split wrist and gripper into moving joints
    Replace the single fixed wrist_gripper_link with four links and add the
    wrist and gripper controls.
    Links:
    wrist_link, gripper_base_link, left_gripper_link, right_gripper_link
    Joints:
    wrist_joint revolute, axis 0 1 0
    gripper_base_joint fixed
    gripper_joint revolute, axis 0 0 1, the single gripper control
    right_gripper_joint revolute, mimic of gripper_joint, multiplier +1
    Joint State Publisher now exposes exactly five controls: base yaw,
    shoulder, elbow, wrist, and gripper. The right gripper side is passive.
    Derivations from the STEP assembly:
    - The wrist frame's Y axis maps exactly onto the forearm frame's Y axis,
    s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
    [robot_arm.urdf.xacro]
2026-09-01 Add dependency-free static model validation
    Add test/validate_model.py, which validates the committed Xacro and STL
    meshes using only the Python standard library, so it runs on the
    development Mac as well as in the Ubuntu VM.
    Checks: xacro expansion, XML parse, single root at base_link, no cycles
    or orphans, no link with two parent joints, all seven required joints
    and their types, exactly five non-mimic controls, mimic target validity
    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
2026-09-01 Add fitted collision geometry and RViz configs
    Add one simplified collision primitive per physical link, fitted to the
    committed meshes rather than hand-estimated.
    Primitive choice is data-driven, not assumed:
    - base_link uses a cylinder. The mesh is genuinely round: 40.5% of its
    vertices lie in the outer 10% of radius, and a cylinder is 21%
    tighter than the bounding box.
    - waist_link uses a box. It looks round but is not - only 8% of
    vertices lie in the outer 10% of radius, so a cylinder would be just
    8% tighter and the box is simpler.
    - The upper arm, forearm, wrist, and gripper base use oriented boxes
    sized to each mesh's own bounding box, inheriting the mesh
    orientation rath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
    [robot_arm.urdf.xacro]
2026-09-01 Add mesh-derived inertial properties
    Give every link mass, centre of mass, and a full inertia tensor obtained
    by integrating the committed STL meshes with the divergence theorem over
    the closed surface, multiplied by pla_density. Nothing is estimated by
    eye.
    The stored values are per-unit-density volume integrals, so changing the
    single pla_density property rescales every mass and every inertia
    correctly. That matters because the analysis workbook's validation item 1
    requires replacing the solid-model density with slicer estimates once
    infill, wall count, and supports are chosen.
    Independent cross-check: this method gives the upper arm 79.78 g. The
    workbook implies 79.71 g for the same par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
    [robot_arm.urdf.xacro]
2026-09-01 Add ros2_control configuration with mock hardware
    Add a ros2_control hardware interface, controller configuration, and a
    control launch path, kept separate from the visualization path so a
    broken controller cannot break the thing that already works.
    urdf/robot_arm.ros2_control.xacro hardware interface macro
    urdf/robot_arm_control.urdf.xacro base model + ros2_control
    config/controllers.yaml broadcaster, arm, gripper
    launch/control.launch.py controller_manager + spawners
    robot_arm.urdf.xacro stays free of control tags; the control variant
    includes it and layers the interface on top.
    Mock hardware is the default. On an ARM64 VM with software rendering,
    mock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
    [controllers.yaml, robot_arm.ros2_control.xacro, robot_arm_control.urdf.xacro]
2026-09-01 Bring progress notes in line with the implemented state
    Record collision, inertial, and ros2_control work in ROS_PROGRESS.md and
    index the simulation guide and validator from README.md. Marks the
    ros2_control layer explicitly as written-but-never-run, and restates the
    current phase as running the model in the VM rather than adding more
    untested layers.
2026-09-01 Fix wrist axes and make the gripper a parallelogram
    Two corrections reported from RViz, both confirmed against the geometry.
    WRIST - the axis was wrong.
    Testing each wrist-frame axis against the forearm's long axis gives
    X 0.011, Y 0.011, Z 0.9999. The previous wrist_joint used Y, so it
    pitched when it should have rolled. Renamed to wrist_roll_joint and moved
    onto Z, which runs along the forearm.
    The pitch belongs one joint further out, where a fixed mount used to be.
    gripper_base_joint becomes wrist_pitch_joint, rotating about the
    gripper-base X axis - exactly perpendicular to the roll axis (dot product
    0.0000) and parallel to the jaw-opening direction, so the jaws stay level
    as the grip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
    [controllers.yaml, robot_arm.ros2_control.xacro, robot_arm.urdf.xacro]
